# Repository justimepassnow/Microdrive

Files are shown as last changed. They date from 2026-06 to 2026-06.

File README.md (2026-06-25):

# μDrive (Microdrive)





**μDrive** is an open-source hardware and software project designed to convert any standard "dumb" DC motor into a smart, closed-loop servo motor. By retrofitting a standard DC motor with an analog potentiometer or an I2C magnetic encoder, μDrive grants you precise control over position, velocity, and current.

---

## ✨ Features

* **Universal DC Motor Support:** Works with standard DC brushed motors (within the limits of the onboard motor driver).
* **Closed-Loop Control:** PID-based control over Motor Position, Velocity, and Torque.
* **Single-Wire Communication:** Network multiple servos together using a half-duplex, single-wire UART interface.
* **Web-Based Dashboard:** Includes a Svelte-based WebGUI utilizing the Web Serial API. Connect a master microcontroller to your PC via USB, and monitor/tune your servo network directly from your browser.
* **High-Level API:** Control motors using high-level commands without worrying about register-level or bit-level operations.

---

## 📖 Documentation

A comprehensive documentation suite is available in the [docs](docs/) directory:
* **[Hardware Reference](docs/hardware.md):** Detailed specs of both board variants, pin mappings, and BOM.
* **[Firmware Guide](docs/firmware.md):** Protocol specifications, PID loop details, and compilation/flashing guide.
* **[Getting Started](docs/getting-started.md):** Step-by-step instructions from zero to a running servo network.
* **[MicroPython API Reference](docs/api-reference.md):** Comprehensive reference for the library, utility scripts, and wiring.

---

## 🛠️ Hardware Specifications

μDrive is available in **two PCB variants** sharing the same MCU and logic, but using different motor drivers:

| Feature | Servo Board | MG996 Drop-in Board |
|---|---|---|
| **Motor Driver** | CP2119 | BDR6121H |
| **Form Factor** | Standard — attach to any DC motor | Drop-in replacement for MG996R servo |
| **Operating Voltage** | Up to 18V max | Up to 7.5V max |
| **Current Rating** | 5A continuous | 1.5A continuous / 3A peak |
| **PCB Files** | [servo_pcb](PCB/) | [servo_pcb_mg99x](PCB/) |

### Board Layouts
<p align="center">
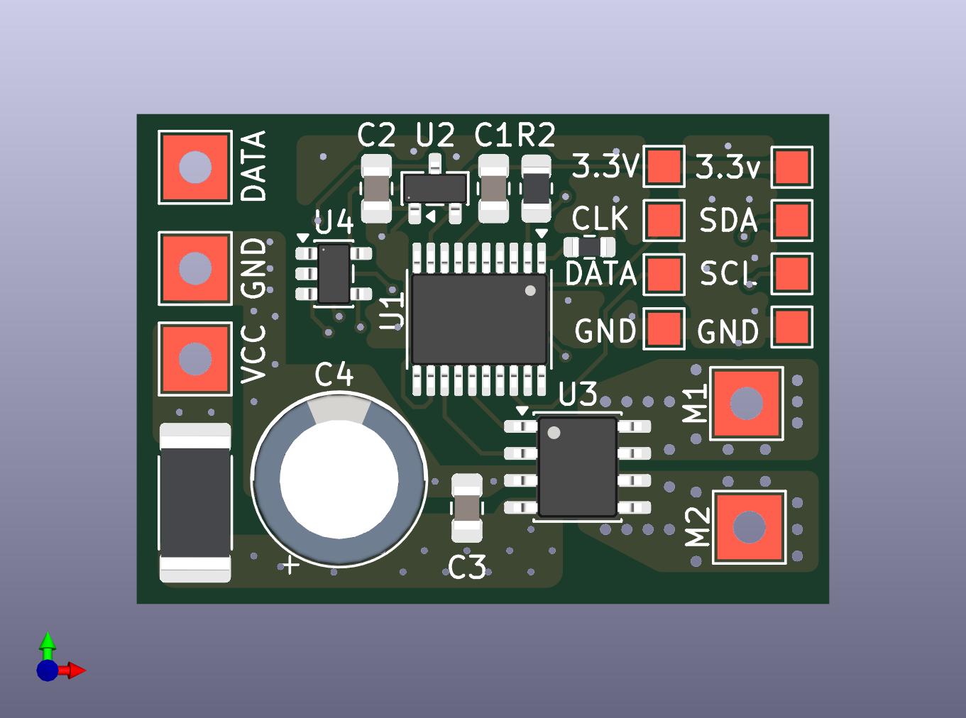
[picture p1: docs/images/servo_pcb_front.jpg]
Servo Board Front
  
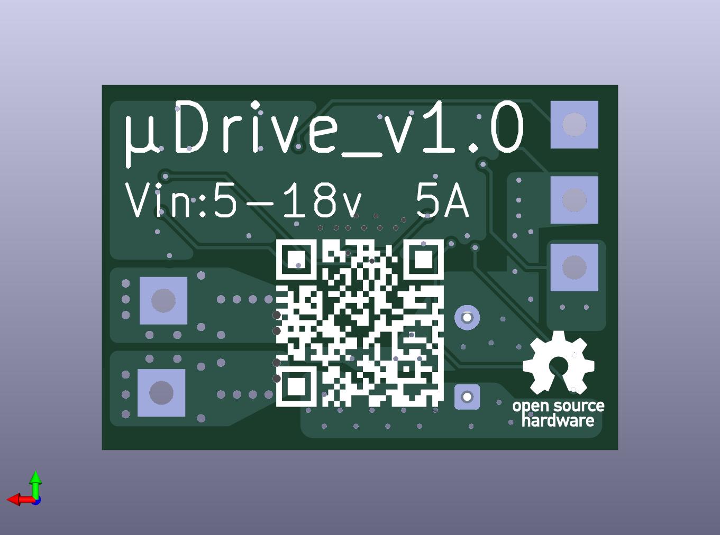
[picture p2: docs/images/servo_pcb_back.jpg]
Servo Board Back
  
</p>

### Common Architecture (Both Boards)
* **Microcontroller:** MindMotion MM32G0001 (32-bit Cortex-M0, 48MHz, 16KB Flash, 2KB RAM)
* **Current Sensor:** INA180A2 (current sense amplifier) with a 0.01Ω shunt resistor for overcurrent protection
* **Power:** Onboard SL7533-3 3.3V logic regulator (supports input up to 24V)
* **Feedback Inputs:**
  * **Analog:** Standard potentiometer support (shared with the SDA pin).
  * **Digital (I2C):** 4-pad footprint (3.3V, SCL, SDA, GND) for external I2C magnetic encoders like the AS5600.
* **Communication:** Half-duplex, single-wire UART on PA12 (open-drain), 250000 baud, 8N1.

---

## 💻 Software & APIs

The project uses a Master/Slave architecture over a half-duplex UART bus. You simply import the driver library onto your master microcontroller and send high-level commands.

* **MicroPython:** A fully functioning driver library is currently available.
* **Arduino/C++:** *Coming soon!*

### WebGUI Architecture

```mermaid
graph TD
    Web["<span style='color:#000'>💻 Web Browser<br>(Svelte WebGUI)</span>"] -- "Web Serial API" --> Master["<span style='color:#000'>🧠 Master Microcontroller<br>(Running Python Script)</span>"]
    Master -- "Single-Wire UART" --> Servo["<span style='color:#000'>⚡ μDrive Servo Board</span>"]
    Servo --> Motor["<span style='color:#000'>⚙️ DC Motor + Encoder</span>"]

    %% Styling
    style Web fill:#e1f5fe,stroke:#01579b,stroke-width:2px;
    style Master fill:#e8f5e9,stroke:#1b5e20,stroke-width:2px;
    style Servo fill:#fff3e0,stroke:#e65100,stroke-width:2px;
    style Motor fill:#efebe9,stroke:#3e2723,stroke-width:2px;
```

<br>

### Web GUI

<p align="center">
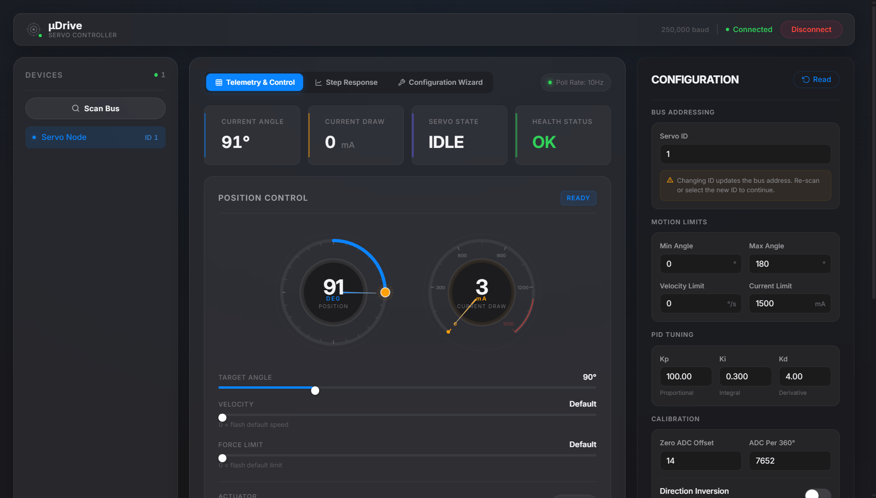
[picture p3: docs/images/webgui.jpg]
μDrive WebGUI Dashboard
  
</p>

<br>

---

## 🚀 Getting Started

### 1. Flashing the Servo Board (via Picoprobe)

> *Why use a Raspberry Pi Pico?*
> Programming obscure chips like the MM32G0001 usually requires buying dedicated, expensive hardware programmers (like mm32link or ST-Link). By using a $4 Raspberry Pi Pico instead, we keep the project incredibly cheap and accessible. Even better: once you've flashed the servo board, you can wipe the Pico and reuse it as the master MicroPython controller for your entire servo network!

**Step 1: Turn the Pico into a Programmer**
Flash your Raspberry Pi Pico with the **Picoprobe** (Debug Probe) firmware to turn it into a CMSIS-DAP debugger. You can download the latest `debugprobe_on_pico.uf2` file directly from the [official Raspberry Pi GitHub Releases page](https://github.com/raspberrypi/debugprobe/releases). Just hold the BOOTSEL button, plug in the Pico, and drag-and-drop the file!

**Step 2: Wire the Pico to the μDrive Board**
Connect these 4 wires from the Pico to the programming header on the μDrive board:
* **Pico 3V3**  -->  **μDrive 3.3V**
* **Pico GND**  -->  **μDrive GND**
* **Pico GP2**  -->  **μDrive SWCLK** (Labeled **C** on the board)
* **Pico GP3**  -->  **μDrive SWDIO** (Labeled **D** on the board)

**Step 3: Install the Software Tools**
1. Install **VS Code** and add the **PlatformIO** extension.
2. Install **Python** on your PC.
3. Open a terminal and install the flashing tool by running: `pip install pyocd`
   * *(**Windows Users:** If `pyocd` fails to detect your probe later, Windows likely installed the wrong default driver. Download the free [Zadig tool](https://zadig.akeo.ie/), select "Picoprobe CMSIS-DAP" from the dropdown, and replace the driver with **WinUSB**).*

**Step 4: Open and Flash!**
1. Clone this repository and open the `Microdrive` folder in VS Code.
2. Click the PlatformIO **Upload** button (the small `→` arrow at the bottom of the screen). PlatformIO will automatically compile the code and trigger `pyocd` to flash it onto the MM32G0001!

### 2. Setting Up the Master MCU (Drivers)
Once the servo board is flashed, it listens for commands over a half-duplex UART line. You will need a "Master" microcontroller to send these commands.
* Currently, a **MicroPython** driver is provided. You can flash a standard Raspberry Pi Pico with MicroPython, import the provided driver library, and use simple high-level functions to command the servo.
* *(Arduino/C++ library support is coming soon!)*

### 3. Launching the Web GUI
To easily tune and monitor your servo network from your computer, you can run the provided Svelte WebGUI:
1. Ensure your Master MCU is connected to your PC via USB and running the serial bridge python script.
2. Open a terminal and navigate to the `gui` folder inside this repository.
3. Run `npm install` to download the web dependencies.
4. Run `npm run dev` to start the local server.
5. Open the provided `localhost` link in a browser that supports the Web Serial API (like Chrome or Edge) to connect to your Master MCU and start tuning!

---

## 🚧 Known Issues & Roadmap

Microdrive is actively under development. Current focus areas include:

* **🐛 EMI Stability:** The board occasionally stops responding to commands during massive current spikes. This is likely due to electromagnetic interference (EMI) crashing the MCU or bus. Hardware/software filtering improvements are being investigated.
* **🚀 Better I2C Encoder Support:** Writing the software drivers to fully utilize the AS5600 footprint.
* **⚙️ Control Optimization:** Improving the efficiency of the communication protocol and fine-tuning the torque and velocity control loops.
* **🔌 Arduino Compatibility:** Development of Arduino/C++ compatible driver libraries to control the servo network from Arduino-compatible microcontrollers.

---

## 🤝 Contributing

Contributions are welcome! Whether it's firmware, hardware, documentation, or the WebGUI — check out the [Contributing Guide](CONTRIBUTING.md) to get started. Found a bug or have an idea? [Open an issue](https://github.com/justimepassnow/Microdrive/issues).

---

## ⚖️ License

This project is fully open-source and [OSHWA certified](https://certification.oshwa.org/in000092.html) (**UID: IN000092**):
* The **Software/Firmware** is licensed under the [MIT License](LICENSE).
* The **Hardware (PCBs/Schematics)** is licensed under the [CERN-OHL-P v2](LICENSE-HARDWARE.txt).

You are free to build, modify, and integrate μDrive into your own projects (commercial or hobbyist).

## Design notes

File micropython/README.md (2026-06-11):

# Microdrive — MicroPython Driver

A lightweight MicroPython library for controlling Microdrives running the MM32 firmware over a half-duplex single-wire UART bus.

## Features

- **Full protocol coverage** — CONTROL, CONFIG, POLL_STATUS, CLEAR_ERROR
- **Half-duplex aware** — built-in TX/RX direction switching with optional GPIO pin
- **Daisy-chain ready** — address servos individually or broadcast to all at once
- **Blocking helpers** — `move_and_wait()` blocks until the servo reaches its target
- **Bus scanner** — discover connected servo IDs
- **Granular or bulk config** — update a single setting or many in one packet
- **Zero dependencies** — only `machine`, `struct`, and `time` (standard MicroPython)

## Wiring

The servo firmware uses **half-duplex single-wire UART** on PA12 (open-drain) at **250000 baud, 8N1**.

### Single-Wire Bus Layout

#### Option A: For boards with open-drain UART support (e.g., ESP32)
If your microcontroller supports native half-duplex UART or allows configuring the TX pin as open-drain, you can connect the TX pin directly to the data bus. No external pull-up is needed because the μDrive PCB already includes an onboard 10kΩ pull-up resistor on the data bus:

```
ESP32 (Open-Drain TX/RX)               μDrive
┌──────────────────┐                   ┌──────────────────┐
│  TX/RX (Pin 4)   ├───────────────────┤ Data Bus         │
│                  │                   │ (Onboard 10kΩ    │
│             GND  ├───────────────────┤  pull-up to 3.3V)│
└──────────────────┘                   └──────────────────┘
```

#### Option B: For boards without open-drain UART support (e.g., Raspberry Pi Pico / RP2040)
If your board does not support open-drain UART, connect the RX pin directly to the bus, and connect the TX pin to the RX pin/bus through a **1kΩ isolation resistor** to prevent short circuits when the MCU TX drives the pin high:

```
MicroPython MCU (Pico)                 μDrive
┌──────────────────┐                   ┌──────────────────┐
│         GP4 (TX) ├────[ 1kΩ Res ]    │                  │
│                  │         │         │                  │
│         GP5 (RX) ├─────────┴─────────┤ Data Bus         │
│                  │                   │ (Onboard 10kΩ    │
│             GND  ├───────────────────┤  pull-up to 3.3V)│
└──────────────────┘                   └──────────────────┘
```

> **Tip:** The 1kΩ resistor acts as isolation. When the Pico transmits a logic low, it pulls the data line down through the resistor. When the servo transmits, the resistor protects the Pico's TX pin if it remains driven high. Since the μDrive board has an onboard 10kΩ pull-up on the Data Bus, no external pull-up resistor is required.

## Quick Start

```python
from machine import UART, Pin
from microdrive import ServoBus

# Create bus (adjust pins for your board)
uart = UART(1, baudrate=250000, tx=Pin(4))
bus  = ServoBus(uart)

# Get a handle to servo at ID 0 (factory default)
servo = bus.servo(0)

# Move to 180 degrees
status = servo.move(180)
print(status)  # <ServoStatus angle=180° current=42mA>

# Poll current state
status = servo.poll()
print(status.angle, status.current_ma, status.is_moving)
```

## API Reference

### `ServoBus(uart, dir_pin=None, reply_timeout_ms=50)`

Manages the shared UART bus.

| Method | Description |
|---|---|
| `servo(id)` | Returns a `Servo` handle for the given ID |
| `broadcast_move(angle, velocity=0)` | Move all servos (no reply) |
| `broadcast_clear_error()` | Clear faults on all servos (no reply) |
| `scan(id_range=range(0,254))` | Scan for connected servos, returns list of `(id, ServoStatus)` |

### `Servo` (returned by `bus.servo(id)`)

#### Movement

| Method | Description |
|---|---|
| `move(angle, velocity=0)` | Send move command. `velocity=0` uses flash default. Returns `ServoStatus` |
| `move_and_wait(angle, velocity=0, timeout_ms=10000)` | Blocking move — returns final `ServoStatus` or `None` on timeout |
| `wait_until_done(timeout_ms=10000, poll_interval_ms=50)` | Block until servo reports idle |
| `is_moving()` | Returns `True` if the servo is currently in motion |

#### Status & Error

| Method | Description |
|---|---|
| `poll()` | Request current status. Returns `ServoStatus` |
| `clear_error()` | Clear overcurrent/stall faults and reset PID state |

#### Configuration (Individual)

| Method | Description |
|---|---|
| `set_id(new_id, direction_invert=False)` | Change bus address (0–127) and motor direction |
| `set_angle_limits(min_angle, max_angle)` | Set software angle limits |
| `set_velocity(max_velocity)` | Set flash-default velocity (deg/s) |
| `set_current_limit(current_limit)` | Set over-current threshold (mA) |
| `set_pid(kp, ki, kd)` | Set PID gains (float → Q16 conversion handled automatically) |
| `set_hard_calibration(hard_min=0, hard_max=300)` | Set potentiometer-to-angle mapping |

#### Configuration (Bulk)

```python
servo.configure(
    servo_id=5,
    direction_invert=False,
    min_angle=45,
    max_angle=280,
    max_velocity=180,
    current_limit=1000,
    kp=100.0, ki=0.05, kd=8.0,
    hard_min=0, hard_max=300,
)
```

Only non-`None` fields are written; others are left untouched on the servo.

### `ServoStatus`

Returned by `move()`, `poll()`, `clear_error()`, and `configure()`.

| Property | Type | Description |
|---|---|---|
| `angle` | int | Current physical angle (degrees) |
| `current_ma` | int | Motor current draw (milliamps) |
| `is_moving` | bool | Servo is actively tracking a target |
| `overcurrent` | bool | Over-current fault flag |
| `stall` | bool | Stall detection fault flag |
| `has_fault` | bool | `True` if any fault is active |
| `servo_id` | int | ID of the servo that replied |
| `instruction` | int | Echoed instruction byte |

## Protocol Reference

See [`../byteorder.md`](../byteorder.md) for the full byte-level packet specification.

## Tested Boards

The library uses only standard MicroPython APIs and should work on any board with a UART peripheral:

- ESP32 / ESP32-S3
- Raspberry Pi Pico (RP2040)
- STM32 (Pyboard)
- ESP8266

## License

Same license as the parent project.

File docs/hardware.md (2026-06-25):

# 🔧 Hardware Documentation

μDrive is an open-source servo controller that turns any standard DC brushed motor into a closed-loop microdrive. This document covers the hardware design, board variants, components, and PCB files.

---

## 📋 Board Variants

Microdrive ships as **two PCB variants**. Both share the same MCU, voltage regulator, current sensor, firmware, and communication protocol. The only difference is the **motor driver IC** and the resulting form factor.

| | Servo Board | MG996 Drop-in Board |
|---|---|---|
| **Motor Driver** | CP2119 | BDR6121H |
| **Form Factor** | Standard — attach to any DC brushed motor | Drop-in replacement for MG996R servo |
| **Operating Voltage** | Up to 18V max | Up to 7.5V max |
| **Current Rating** | 5A continuous | 1.5A continuous / 3A peak |
| **Schematic** | `servo_pcb.kicad_sch` | `servo_pcb_mg99x.kicad_sch` |
| **PCB Layout** | `servo_pcb.kicad_pcb` | `servo_pcb_mg99x.kicad_pcb` |

> [!TIP]
> Both boards run identical firmware. Choose the variant that fits your mechanical design — or use the Servo Board as a universal motor controller.

---

## ⚙️ Common Specifications

| Parameter | Value |
|---|---|
| **MCU** | MindMotion MM32G0001 (32-bit ARM Cortex-M0, 48 MHz) |
| **Flash / RAM** | 16 KB / 2 KB |
| **Voltage Regulator** | SL7533-3 (3.3V LDO, input up to 24V) |
| **Current Sensor** | INA180A2 (current sense amplifier) with 0.01Ω shunt (R1, 2512 package) |
| **Motor PWM** | TIM1 CH2 (PA8) / CH3 (PA6), 20 kHz, H-bridge control |
| **Communication** | Half-duplex single-wire UART on PA12 (open-drain), 250000 baud, 8N1 |
| **Programming** | SWD via SWCLK and SWDIO test pads (use Picoprobe / CMSIS-DAP) |

### Feedback Options

μDrive supports two mutually exclusive feedback mechanisms:

| Feedback Type | Details |
|---|---|
| **Analog Potentiometer** | Connected to PA7 (ADC Channel 7). Shared with the SDA pin on the I2C header. |
| **I2C Magnetic Encoder** | AS5600 footprint with 4-pad header: 3.3V, SCL, SDA, GND. *(Hardware ready, software planned.)* |

> [!NOTE]
> The potentiometer input and the SDA pin share the same physical trace on the PCB. You can use one or the other — not both simultaneously.

---

## 🗺️ Pin Mapping (MM32G0001 — TSSOP-20)

| Pin | Function | Notes |
|---|---|---|
| PA12 | UART TX/RX | Half-duplex single-wire bus (open-drain, AF1) |
| PA6 | TIM1 CH3 (PWM) | H-bridge output A (AF4). Also heartbeat LED in debug. |
| PA8 | TIM1 CH2 (PWM) | H-bridge output B (AF1) |
| PA7 | ADC Channel 7 | Potentiometer feedback (analog input) |
| PA5 | I2C SCL | Clock line for optional AS5600 encoder / SCL test pad (AF1) |
| PA4 | I2C SDA | Tied to PA7 on PCB — digital buffer disabled for noise reduction (SDA) |
| PA2 | ADC Channel 5 | Current sense amplifier output (INA180A2) |
| PA0 | GPIO Input (Pull-Up) | Software reset button |
| SWCLK | SWD Clock | Programming/debug pad |
| SWDIO | SWD Data | Programming/debug pad |

---

## 📦 Bill of Materials

| Designator | Package | Value | Component |
|---|---|---|---|
| U1 | TSSOP-20 | MM32G0001 | MCU |
| U2 | SOT-23 | SL7533-3 | 3.3V LDO Regulator |
| U3 | SOIC-8 | BDR6121H *(MG996)* / CP2119 *(Servo Board)* | Motor Driver |
| U4 | SOT-23-5 | INA180A2 | Current Sense Amplifier |
| U5 | SOIC-8 | AS5600 | I2C Magnetic Encoder *(optional)* |
| R1 | 2512 | 0.01Ω | Current Sense Shunt Resistor |
| R2, R3, R4 | 0805 | 10KΩ | Pull-up / Pull-down Resistors |
| C1, C4 | 0805 | 10μF | Decoupling Capacitors |
| C2, C3, C5 | 0805 | 100nF | Bypass Capacitors |
| J1 | Pin Header 1×03, P2.54mm | Power In | Power Connector |

### Test Pads

The PCB exposes the following test pads for probing and programming:

| Pad | Description |
|---|---|
| 3.3V | Regulated logic supply |
| GND | Ground |
| SDA | I2C data / Potentiometer analog signal |
| SCL | I2C clock |
| SWCLK | SWD clock (labeled **C** on the board) |
| SWDIO | SWD data (labeled **D** on the board) |
| +VE | Motor positive terminal |
| -VE | Motor negative terminal |

## 📁 PCB Files

All hardware design files are located in the [`PCB/`](../PCB/) directory of the repository. The project uses **KiCad** as the EDA tool.

### File Listing

| File | Description |
|---|---|
| `servo_pcb.kicad_sch` | Servo Board schematic |
| `servo_pcb.kicad_pcb` | Servo Board PCB layout |
| `servo_pcb.kicad_pro` | Servo Board KiCad project |
| `servo_pcb-mg99x.kicad_sch` | MG996 drop-in board schematic |
| `servo_pcb_mg99x.kicad_pcb` | MG996 drop-in board PCB layout |
| `servo_pcb_mg99x.kicad_pro` | MG996 drop-in board KiCad project |

### Custom Symbol Libraries

| File | Component |
|---|---|
| `mm32g0001a1t.kicad_sym` | MM32G0001 MCU |
| `BDR6121H.kicad_sym` | BDR6121H motor driver |
| `CP2119L.kicad_sym` | CP2119 motor driver |
| `AS5600.kicad_sym` | AS5600 magnetic encoder |
| `sl7533-3.kicad_sym` | SL7533-3 voltage regulator |

## ⚖️ Licensing

| Component | License |
|---|---|
| Hardware (PCBs / Schematics) | [CERN-OHL-P v2](../LICENSE-HARDWARE.txt) |
| Software / Firmware | [MIT License](../LICENSE) |

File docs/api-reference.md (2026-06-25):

# 📖 MicroPython API Reference

Complete API documentation for the `microdrive.py` driver library.

**Source:** [`micropython/microdrive.py`](../micropython/microdrive.py)

---

## Table of Contents

- [Quick Start](#quick-start)
- [ServoBus](#servobus)
- [Servo](#servo)
  - [Movement](#movement)
  - [Status & Error](#status--error)
  - [Configuration (Individual)](#configuration-individual)
  - [Configuration (Bulk)](#configuration-bulk)
  - [Convenience](#convenience)
- [ServoStatus](#servostatus)
- [ServoConfigData](#servoconfigdata)
- [Protocol Details](#protocol-details)
- [Wiring Diagrams](#wiring-diagrams)
- [Utility Scripts](#utility-scripts)

---

## Quick Start

```python
from machine import UART, Pin
from microdrive import ServoBus

uart = UART(1, baudrate=250000, tx=Pin(4), rx=Pin(5))
bus  = ServoBus(uart)
servo = bus.servo(0)

# Move to 180° at default velocity
servo.move(180)

# Poll current state
status = servo.poll()
print(status)  # <ServoStatus angle=180° current=42mA>
```

---

## ServoBus

```python
ServoBus(uart, dir_pin=None, reply_timeout_ms=5)
```

Manages the shared half-duplex UART bus for one or more Microdrives.

### Parameters

| Parameter | Type | Default | Description |
|---|---|---|---|
| `uart` | `machine.UART` | *(required)* | Pre-configured UART instance at **250,000 baud, 8N1**. TX pin wired to the servo bus line. |
| `dir_pin` | `machine.Pin` or `None` | `None` | Optional direction control pin (active-high = transmit). Set to `None` if the UART handles half-duplex natively or if using a shared open-drain TX/RX line. |
| `reply_timeout_ms` | `int` | `5` | Milliseconds to wait for a servo reply before giving up. The firmware replies in ~2.7 ms on average. |

### Methods

#### `servo(servo_id) → Servo`

Create a `Servo` handle bound to this bus.

| Parameter | Type | Description |
|---|---|---|
| `servo_id` | `int` | The servo's bus address (**0–127**). ID 0 targets factory-default / unconfigured servos. |

```python
servo = bus.servo(0)
```

---

#### `broadcast_move(angle, velocity=0, current=0)`

Move **all** servos on the bus simultaneously. No reply is expected (broadcast address `0xFE`).

| Parameter | Type | Default | Description |
|---|---|---|---|
| `angle` | `int` | *(required)* | Target angle in degrees |
| `velocity` | `int` | `0` | Temporary velocity in deg/s. `0` = use each servo's flash default |
| `current` | `int` | `0` | Temporary current/force limit in mA. `0` = use each servo's flash default |

```python
bus.broadcast_move(90, velocity=200)
```

---

#### `broadcast_clear_error()`

Clear faults on **all** servos (no reply expected). Also resets PID state and locks the target angle to the current physical position on each servo.

```python
bus.broadcast_clear_error()
```

---

#### `broadcast_disarm()`

Disarm all servos on the bus, turning off H-bridges so that all servo shafts spin completely freely. This is an alias for `broadcast_clear_error()`.

```python
bus.broadcast_disarm()
```

---

#### `scan(id_range=range(0, 128)) → list[(int, ServoStatus)]`

Scan the bus for connected servos by polling each ID in the range.

Returns a list of `(servo_id, ServoStatus)` tuples for every servo that replied.

| Parameter | Type | Default | Description |
|---|---|---|---|
| `id_range` | `range` | `range(0, 128)` | Range of IDs to scan |

> [!NOTE]
> Scanning is slow — each non-responding ID waits for the full reply timeout. Narrow the range if you know the expected IDs.

```python
found = bus.scan(id_range=range(0, 10))
for sid, status in found:
    print(f"ID {sid}: {status.angle}° {status.current_ma}mA")
```

---

## Servo

```python
# Do not instantiate directly — use bus.servo(id) instead
servo = bus.servo(1)
```

High-level interface to a single Microdrive on the bus.

### Properties

| Property | Type | Description |
|---|---|---|
| `id` | `int` | This servo's bus address (read-only) |

---

### Movement

#### `move(angle, velocity=0, current=0) → None`

Command the servo to move to the target angle. Returns immediately (fire-and-forget, no reply expected).

| Parameter | Type | Default | Description |
|---|---|---|---|
| `angle` | `int` | *(required)* | Target angle in degrees (clamped to configured limits) |
| `velocity` | `int` | `0` | Temporary movement speed in deg/s. `0` = use flash default |
| `current` | `int` | `0` | Temporary force/current limit in mA. `0` = use flash default |

```python
servo.move(90)
servo.move(180, velocity=300, current=800)
```

> [!IMPORTANT]
> The motor **does not move** until the first `move()` command is received after power-on. This is a safety feature — the H-bridge stays off until then.

---

#### `move_and_wait(angle, velocity=0, timeout_ms=10000) → ServoStatus | None`

Send a move command and **block** until the servo reports it has reached the target (i.e., `is_moving` becomes `False`).

| Parameter | Type | Default | Description |
|---|---|---|---|
| `angle` | `int` | *(required)* | Target angle in degrees |
| `velocity` | `int` | `0` | Temporary velocity in deg/s |
| `timeout_ms` | `int` | `10000` | Max time to wait before returning `None` |

Returns the final `ServoStatus`, or `None` on timeout.

```python
status = servo.move_and_wait(180, velocity=200, timeout_ms=5000)
if status:
    print(f"Arrived at {status.angle}°")
```

---

#### `wait_until_done(timeout_ms=10000, poll_interval_ms=50) → ServoStatus | None`

Block until the servo reports it has finished moving, or until timeout. Polls the servo at the given interval.

| Parameter | Type | Default | Description |
|---|---|---|---|
| `timeout_ms` | `int` | `10000` | Max time to wait |
| `poll_interval_ms` | `int` | `50` | Polling interval |

```python
servo.move(90)
# ... do other work ...
final = servo.wait_until_done()
```

---

#### `is_moving() → bool`

Poll the servo and return `True` if it is currently in motion.

```python
if servo.is_moving():
    print("Still moving...")
```

---

### Status & Error

#### `poll() → ServoStatus | None`

Request the servo's current status without changing anything. Returns a `ServoStatus` object, or `None` on timeout.

```python
status = servo.poll()
if status:
    print(f"{status.angle}° — {status.current_ma} mA")
```

---

#### `clear_error() → None`

Clear the overcurrent fault flag, reset PID integrator memory, and lock the target angle to the servo's current physical position.

```python
servo.clear_error()
```

---

#### `disarm() → None`

Disarm the motor H-bridge, disabling power so the shaft spins freely. The servo re-arms automatically upon the next `move()` command. This is an alias for `clear_error()`.

```python
servo.disarm()
```

---

### Configuration (Individual)

Each setter sends a fixed-length CONFIG packet with only its corresponding update-mask bit set. The firmware ignores all fields whose mask bits are not active.

> [!NOTE]
> Configuration changes are **saved to flash** by default and persist across power cycles. Use the `ram_only=True` flag on `set_pid()` or `configure()` to apply changes temporarily (useful for rapid PID tuning without wearing out flash).

---

#### `set_id(new_id, direction_invert=False) → ServoStatus | None`

Change the servo's bus address and/or motor direction.

| Parameter | Type | Default | Description |
|---|---|---|---|
| `new_id` | `int` | *(required)* | New servo ID (**0–127**). 0 = unconfigured. |
| `direction_invert` | `bool` | `False` | `True` to invert the motor rotation direction |

```python
servo.set_id(5)
# After changing the ID, create a new handle:
servo = bus.servo(5)
```

> [!WARNING]
> After changing the ID, the old `Servo` handle is stale. Always create a new one with `bus.servo(new_id)`.

---

#### `set_angle_limits(min_angle, max_angle) → ServoStatus | None`

Set the software-enforced angle limits (degrees). The servo will clamp any move command to these bounds.

| Parameter | Type | Description |
|---|---|---|
| `min_angle` | `int` | Minimum allowable target angle |
| `max_angle` | `int` | Maximum allowable target angle |

```python
servo.set_angle_limits(0, 180)
```

---

#### `set_velocity(max_velocity) → ServoStatus | None`

Set the flash-stored default velocity limit in degrees per second. This is used when `velocity=0` is passed to `move()`.

| Parameter | Type | Description |
|---|---|---|
| `max_velocity` | `int` | Default maximum velocity (deg/s) |

```python
servo.set_velocity(200)
```

---

#### `set_current_limit(current_limit) → ServoStatus | None`

Set the over-current fault threshold in milliamps.

| Parameter | Type | Description |
|---|---|---|
| `current_limit` | `int` | Current draw threshold (mA) |

```python
servo.set_current_limit(1000)
```

---

#### `set_pid(kp=None, ki=None, kd=None, ram_only=False) → ServoStatus | None`

Set PID gains. Accepts **float** values — they are converted to Q16.16 fixed-point internally.

| Parameter | Type | Default | Description |
|---|---|---|---|
| `kp` | `float` or `None` | `100.0` | Proportional gain |
| `ki` | `float` or `None` | `0.05` | Integral gain |
| `kd` | `float` or `None` | `8.0` | Derivative gain |
| `ram_only` | `bool` | `False` | If `True`, update RAM only (skip flash save) |

> [!IMPORTANT]
> All three gains are written as a group. If you pass `None` for any gain, the firmware default is used (Kp=100.0, Ki=0.05, Kd=8.0). Always provide all three values together when tuning.

```python
# Tune PID in RAM (fast iteration, no flash wear)
servo.set_pid(kp=80.0, ki=0.03, kd=12.0, ram_only=True)

# Save final values to flash
servo.set_pid(kp=80.0, ki=0.03, kd=12.0)
```

---

#### `set_calibration(zero_adc, adc_per_360) → ServoStatus | None`

Set the physical ADC calibration mapping for the potentiometer.

| Parameter | Type | Description |
|---|---|---|
| `zero_adc` | `int` | Raw ADC value corresponding to 0° |
| `adc_per_360` | `int` | Number of ADC ticks for a full 360° rotation |

```python
servo.set_calibration(zero_adc=120, adc_per_360=3200)
```

> [!TIP]
> Use the `manual_angle_calibrate.py` utility script to determine these values precisely for your motor.

---

### Configuration (Bulk)

#### `configure(...) → ServoStatus | None`

Update multiple configuration fields in a **single** CONFIG packet. Only the provided (non-`None`) fields are written; all others are left untouched on the servo.

```python
configure(
    servo_id=None,           # int: New bus address (0–127)
    direction_invert=None,   # bool: Invert motor direction
    min_angle=None,          # int: Minimum angle limit (degrees)
    max_angle=None,          # int: Maximum angle limit (degrees)
    max_velocity=None,       # int: Default velocity (deg/s)
    current_limit=None,      # int: Over-current threshold (mA)
    kp=None,                 # float: Proportional PID gain
    ki=None,                 # float: Integral PID gain
    kd=None,                 # float: Derivative PID gain
    zero_adc=None,           # int: Raw ADC at 0°
    adc_per_360=None,        # int: ADC ticks per 360°
    ram_only=False           # bool: Skip flash write
)
```

**Example — full initial configuration:**

```python
servo.configure(
    servo_id=1,
    direction_invert=False,
    min_angle=0,
    max_angle=200,
    max_velocity=180,
    current_limit=1000,
    kp=100.0, ki=0.05, kd=8.0,
)
```

**Example — change just the velocity:**

```python
servo.configure(max_velocity=300)
```

> [!NOTE]
> Angle limits (`min_angle`, `max_angle`) and calibration values (`zero_adc`, `adc_per_360`) must be provided **as a pair** — you cannot update one without the other.

---

#### `read_config() → ServoConfigData | None`

Request the servo's full persistent configuration stored in flash memory.

```python
config = servo.read_config()
if config:
    print(f"ID: {config.servo_id}")
    print(f"Limits: {config.min_angle}° – {config.max_angle}°")
    print(f"PID: Kp={config.kp:.2f} Ki={config.ki:.4f} Kd={config.kd:.2f}")
```

---

## ServoStatus

Returned by `poll()`, `move_and_wait()`, `wait_until_done()`, and configuration methods (when not broadcasting).

| Property | Type | Description |
|---|---|---|
| `angle` | `int` | Current physical angle in degrees (signed, can be negative) |
| `current_ma` | `int` | Motor current draw in milliamps |
| `is_moving` | `bool` | `True` if the servo is actively tracking a target |
| `overcurrent` | `bool` | `True` if an over-current fault is active |
| `is_holding` | `bool` | `True` if admittance yield mode is active (motor is complying/backdriving due to current limiting) |
| `has_fault` | `bool` | `True` if **any** fault flag is active (currently = `overcurrent`) |
| `servo_id` | `int` | Bus address of the servo that replied |
| `instruction` | `int` | Echoed instruction byte from the request |

**String representation:**

```python
>>> status = servo.poll()
>>> print(status)
<ServoStatus angle=90° current=42mA flags=HOLDING>
```

---

## ServoConfigData

Returned by `servo.read_config()`. Contains the persistent configuration stored in flash.

| Property | Type | Description |
|---|---|---|
| `servo_id` | `int` | Bus address (0–127) |
| `direction_invert` | `bool` | Whether motor direction is inverted |
| `min_angle` | `int` | Software minimum angle limit (degrees) |
| `max_angle` | `int` | Software maximum angle limit (degrees) |
| `max_velocity` | `int` | Default velocity in deg/s |
| `current_limit` | `int` | Over-current fault threshold in mA |
| `kp` | `float` | Proportional PID gain (converted from Q16) |
| `ki` | `float` | Integral PID gain (converted from Q16) |
| `kd` | `float` | Derivative PID gain (converted from Q16) |
| `zero_adc` | `int` | Raw ADC value at 0° |
| `adc_per_360` | `int` | ADC ticks per full 360° rotation |
| `magic` | `int` | Flash validity marker |

**String representation:**

```python
>>> config = servo.read_config()
>>> print(config)
<ServoConfigData id=1 dir_invert=False limits=0°-200° max_vel=180
 current_lim=1000mA kp=100.00 ki=0.0500 kd=8.00
 zero_adc=120 adc_per_360=3200 magic=0xCAFE>
```

---

## Protocol Details

The servo bus uses a binary packet protocol over half-duplex UART:

| Field | Description |
|---|---|
| **Header** | `0xFF 0xFF` (2 bytes) |
| **Servo ID** | Target address (1 byte, `0xFE` = broadcast) |
| **Length** | Number of remaining bytes: instruction + params + checksum |
| **Instruction** | Command byte (see below) |
| **Parameters** | Little-endian payload (variable length) |
| **Checksum** | `~(sum of ID + Length + Instruction + Params) & 0xFF` |

### Instruction Codes

| Code | Name | Direction | Description |
|---|---|---|---|
| `0x01` | `CONTROL` | Master → Servo | Move command (angle, velocity, current) |
| `0x02` | `CONFIG` | Master → Servo | Write configuration fields |
| `0x03` | `POLL` | Master → Servo | Request status (servo replies with 11-byte status) |
| `0x04` | `CLEAR_ERR` | Master → Servo | Clear faults, reset PID, disarm H-bridge |
| `0x05` | `READ_CONFIG` | Master → Servo | Read flash config (servo replies with 36-byte config) |

### Reply Packet Sizes

| Reply Type | Total Bytes |
|---|---|
| **Status reply** | 11 bytes |
| **Config reply** | 36 bytes |

---

## Wiring Diagrams

### Single-Wire Bus Layout

#### Option A: For boards with open-drain UART support (e.g., ESP32)
If your microcontroller supports native half-duplex UART or allows configuring the TX pin as open-drain, you can connect the TX pin directly to the data bus. No external pull-up is needed because the μDrive PCB already includes an onboard 10kΩ pull-up resistor on the data bus:

```mermaid
graph LR
    subgraph MCU["ESP32 (Open-Drain TX/RX)"]
        Pin["<span style='color:#000'>TX/RX (Pin 4)</span>"]
        GND1["<span style='color:#000'>GND</span>"]
    end
    subgraph Servo["μDrive Board"]
        Data["<span style='color:#000'>Data Bus (PA12)<br>(Onboard 10kΩ pull-up)</span>"]
        GND2["<span style='color:#000'>GND</span>"]
    end
    Pin --- Data
    GND1 --- GND2

    style Pin fill:#e1f5fe,stroke:#01579b,stroke-width:2px;
    style Data fill:#fff3e0,stroke:#e65100,stroke-width:2px;
    style GND1 fill:#efebe9,stroke:#3e2723,stroke-width:2px;
    style GND2 fill:#efebe9,stroke:#3e2723,stroke-width:2px;
```

#### Option B: For boards without open-drain UART support (e.g., Raspberry Pi Pico / RP2040)
If your board does not support open-drain UART, do **not** tie the TX and RX pins directly together. Instead, connect the RX pin directly to the servo data bus, and connect the TX pin to the RX pin/bus through a **1kΩ isolation resistor**. This protects the TX pin from short circuits when the MCU TX drives the pin high while the servo drives the bus low:

```mermaid
graph LR
    subgraph MCU["MicroPython MCU"]
        TX["<span style='color:#000'>GP4 (TX)</span>"]
        RX["<span style='color:#000'>GP5 (RX)</span>"]
        GND1["<span style='color:#000'>GND</span>"]
    end
    subgraph Servo["μDrive Board"]
        Data["<span style='color:#000'>Data Bus (PA12)<br>(Onboard 10kΩ pull-up)</span>"]
        GND2["<span style='color:#000'>GND</span>"]
    end
    Res["<span style='color:#000'>1kΩ Resistor</span>"]

    TX --- Res
    RX --- Res
    RX --- Data
    GND1 --- GND2

    style TX fill:#e1f5fe,stroke:#01579b,stroke-width:2px;
    style RX fill:#e1f5fe,stroke:#01579b,stroke-width:2px;
    style Res fill:#f3e5f5,stroke:#7b1fa2,stroke-width:2px;
    style Data fill:#fff3e0,stroke:#e65100,stroke-width:2px;
    style GND1 fill:#efebe9,stroke:#3e2723,stroke-width:2px;
    style GND2 fill:#efebe9,stroke:#3e2723,stroke-width:2px;
```

> [!TIP]
> - The **1kΩ resistor** acts as an isolation resistor between the TX and RX/data line on the MCU side. When the MCU transmits a logic low, it pulls the data line down through the resistor. When the servo transmits, the resistor protects the microcontroller's TX pin if it remains driven high.
> - The μDrive board has an onboard **10kΩ pull-up resistor** on the Data Bus, so no external pull-up is required. An external pull-up (e.g., 4.7kΩ to 3.3V) is only needed if your custom master or bus setup lacks one.

---

## Utility Scripts

The `micropython/` folder includes several ready-to-use scripts:

| Script | Description |
|---|---|
| [example.py](../micropython/example.py) | Interactive quick-start & configuration utility. Scans for servos, shows telemetry, and enters a move-and-track loop with real-time status printing. |
| [calibrate_pid.py](../micropython/calibrate_pid.py) | **Automated PID tuner** using a gradient-ascent step-response algorithm. Finds the friction floor (Kp), determines the spring limit, damps overshoot (Kd), and injects integral gain (Ki). Saves results to flash. |
| [hard_angle_set.py](../micropython/hard_angle_set.py) | **Automatic hard-limit calibration.** Sweeps the servo to measure average dynamic current, then slowly probes in each direction until a current spike reveals the physical end-stops. Saves `min_angle` and `max_angle` to flash. |
| [manual_angle_calibrate.py](../micropython/manual_angle_calibrate.py) | **Manual multi-point potentiometer calibration.** Temporarily sets ADC scale to 1:1 so `angle` telemetry mirrors the raw ADC, then prompts you to align the shaft to 0° and 90° by hand. Computes and saves `zero_adc` and `adc_per_360`. |
| [serial_proxy.py](../micropython/serial_proxy.py) | **Serial bridge for the WebGUI.** Reads JSON commands from USB `stdin`, translates them to servo bus packets, and returns JSON responses. Supports `scan`, `move`, `poll`, `read_config`, `configure`, and `clear_error` commands. |
| [stream_current.py](../micropython/stream_current.py) | **Real-time current monitor.** Continuously polls and prints the servo's current draw — useful for verifying current sensing against a multimeter. |
| [speedtest.py](../micropython/speedtest.py) | **Feature & config sweep test.** Verifies scanning, config read/write, fault clearing, and runs a continuous angle sweep (20°→220°→20° in 40° steps) with real-time telemetry at each step. |

### Running Utility Scripts

1. Copy `microdrive.py` and the desired script onto the microcontroller.
2. Connect the servo bus and power supply.
3. Open a serial terminal (Thonny, `mpremote`, PuTTY) and run:

```python
import calibrate_pid  # or any other script
```

---

## Tested Boards

The driver uses only standard MicroPython APIs and should work on any board with a UART peripheral:

- ✅ Raspberry Pi Pico / Pico W (RP2040)
- ✅ ESP32 / ESP32-S3
- ✅ STM32 (Pyboard)
- ✅ ESP8266

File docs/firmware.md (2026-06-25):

# 💻 Firmware Documentation

The μDrive firmware is a bare-metal C application running on the MindMotion MM32G0001 (ARM Cortex-M0). It implements closed-loop position control with velocity trajectory profiling, overcurrent protection, and a binary packet communication protocol — all in 16 KB of Flash and 2 KB of RAM.

---

## 🏗️ Architecture Overview

| Parameter | Value |
|---|---|
| **Language** | C (bare-metal, no RTOS) |
| **MCU** | MM32G0001 — ARM Cortex-M0, TSSOP-20 |
| **System Clock** | 48 MHz (HSI, configured in `SystemInit()`) |
| **Flash** | 16 KB (0x08000000 – 0x08003FFF) |
| **RAM** | 2 KB (0x20000000 – 0x200007FF) |
| **Stack** | 512 bytes |
| **PID Loop Rate** | 1 ms (via SysTick interrupt) |
| **Motor PWM** | 20 kHz (TIM1, no prescaler) |
| **Arithmetic** | Q8 and Q16 fixed-point (no FPU on Cortex-M0) |

### Boot Sequence

1. `Reset_Handler` — Copies `.data` from Flash to RAM, zeroes `.bss`
2. `SystemInit()` — Configures HSI to 48 MHz, sets flash latency
3. `main()` — Initializes UART, loads flash config, configures TIM1 PWM, initializes ADC, calibrates current sensor, enables SysTick

### Source Files

| File | Purpose |
|---|---|
| `src/main.c` | Application logic: UART, protocol parser, PID controller, ADC, flash storage |
| `src/startup.c` | Vector table, `Reset_Handler`, weak IRQ symbol definitions |
| `src/hal_adc.c` | MindMotion HAL — ADC driver |
| `src/hal_gpio.c` | MindMotion HAL — GPIO driver |
| `src/hal_misc.c` | MindMotion HAL — NVIC utilities |
| `src/hal_rcc.c` | MindMotion HAL — Clock configuration |
| `src/hal_tim.c` | MindMotion HAL — Timer driver |
| `src/hal_usart.c` | MindMotion HAL — USART driver |
| `custom.ld` | Custom linker script (2 KB RAM, 16 KB Flash) |

---

## 📡 Communication Protocol

μDrive uses a **half-duplex single-wire UART** bus on **PA12** (open-drain) at **250000 baud, 8N1**. Multiple servos can share the same bus using unique IDs.

### Packet Format

All communication uses a binary packet format:

```text
┌──────┬──────┬──────┬────────┬─────────────┬──────────┬──────────┐
│ 0xFF │ 0xFF │  ID  │ Length │ Instruction │ Params…  │ Checksum │
└──────┴──────┴──────┴────────┴─────────────┴──────────┴──────────┘
```

| Field | Size | Description |
|---|---|---|
| Header | 2 bytes | Always `0xFF 0xFF` |
| ID | 1 byte | Target servo ID (`0`–`127`), or `0xFE` for broadcast |
| Length | 1 byte | Number of bytes following: `Instruction + Params + Checksum` |
| Instruction | 1 byte | Command opcode (see below) |
| Params | 0–N bytes | Instruction-specific payload |
| Checksum | 1 byte | `~(ID + Length + Instruction + Params) & 0xFF` |

> [!NOTE]
> Broadcast ID `0xFE` sends a command to all servos on the bus. No reply is generated for broadcast packets.

### Instructions

| Opcode | Name | Direction | Description |
|---|---|---|---|
| `0x01` | CONTROL | Master → Servo | Move to target angle with optional velocity and current limit |
| `0x02` | CONFIG | Master → Servo | Update configuration fields (with bitmask for partial updates) |
| `0x03` | POLL | Master → Servo | Request current status |
| `0x04` | CLEAR_ERROR | Master → Servo | Clear overcurrent faults and reset PID state |
| `0x05` | READ_CONFIG | Master → Servo | Read current flash configuration |

---

### 0x01 — CONTROL

Moves the servo to a target angle with optional velocity and current limit overrides.

**Parameters (4 or 6 bytes):**

| Byte | Field | Type | Description |
|---|---|---|---|
| 0–1 | `angle` | uint16 LE | Target angle in degrees |
| 2–3 | `velocity` | uint16 LE | Velocity in deg/s (`0` = use config default) |
| 4–5 | `current` | uint16 LE | Current limit in mA (`0` = use config default). *Optional.* |

**Behavior:**
- Angle is clamped to `[min_angle, max_angle]` from the config
- Arms the motor on the first valid CONTROL packet
- Ignored if an overcurrent fault is active
- No status reply is sent (for maximum control loop throughput)

---

### 0x02 — CONFIG

Updates one or more configuration fields. A **bitmask** in the first parameter byte selects which fields to write. Unselected fields remain unchanged.

**Parameters (up to 26 bytes):**

| Byte | Field | Bitmask Bit | Description |
|---|---|---|---|
| 0 | `update_mask` | — | Bitmask selecting which fields to update |
| 1 | `id_and_dir` | Bit 0 | Lower 7 bits = `servo_id`, MSB = `direction_invert` |
| 2–3 | `min_angle` | Bit 1 | Minimum angle limit (uint16 LE) |
| 4–5 | `max_angle` | Bit 1 | Maximum angle limit (uint16 LE) |
| 6–7 | `max_velocity` | Bit 2 | Default velocity, deg/s (uint16 LE) |
| 8–9 | `current_limit` | Bit 3 | Overcurrent threshold, mA (uint16 LE) |
| 10–13 | `kp_q16` | Bit 4 | Proportional gain, Q16 (int32 LE) |
| 14–17 | `ki_q16` | Bit 4 | Integral gain, Q16 (int32 LE) |
| 18–21 | `kd_q16` | Bit 4 | Derivative gain, Q16 (int32 LE) |
| 22–23 | `zero_adc` | Bit 5 | ADC value at 0° (int16 LE) |
| 24–25 | `adc_per_360` | Bit 5 | ADC ticks per 360° rotation (int16 LE) |

**Special flag — Bit 6 (Volatile):**
- If Bit 6 of `update_mask` is **set**, the config update is **RAM-only** (not persisted to flash).
- If Bit 6 is **clear**, the config is written to flash.

**Reply:** Status packet (11 bytes) echoing instruction `0x02`.

---

### 0x03 — POLL

Requests the servo's current status. No parameters.

**Reply:** Status packet (11 bytes).

---

### 0x04 — CLEAR_ERROR

Clears an overcurrent fault and resets the PID state.

**Parameters (1 byte):**

| Byte | Value | Description |
|---|---|---|
| 0 | `1` | Clear error flag, reset PID, disarm motor |

**Behavior:**
- Clears `overcurrent_fault` and `overcurrent_ms`
- Resets PID integral and derivative state
- Disarms motor (allows manual shaft positioning)
- Sets the target and ghost angles to the current physical angle

---

### 0x05 — READ_CONFIG

Reads the full configuration from the servo.

**Reply:** Config packet (36 bytes) — header + full `ServoConfig` struct as parameters.

---

### Status Reply Packet (11 bytes)

Sent in response to POLL or CONFIG commands:

```text
┌──────┬──────┬──────┬──────┬─────────────┬───────────────────────────────────┬──────────┐
│ 0xFF │ 0xFF │  ID  │ 0x07 │ Instruction │  angle(2) current(2) flags(1)    │ Checksum │
└──────┴──────┴──────┴──────┴─────────────┴───────────────────────────────────┴──────────┘
```

| Param Bytes | Field | Type | Description |
|---|---|---|---|
| 0–1 | `current_angle` | uint16 LE | Current servo angle in degrees |
| 2–3 | `current_ma` | uint16 LE | Current motor draw in milliamps |
| 4 | `flags` | uint8 | Status flags (see below) |

**Status Flags:**

| Bit | Name | Description |
|---|---|---|
| 0 | `MOVING` | Servo is actively tracking a target |
| 1 | `OVERCURRENT` | Overcurrent fault is active |
| 2 | `HOLDING` | Admittance yield mode is active (compliant holding) |

### Config Reply Packet (36 bytes)

Sent in response to READ_CONFIG:

```text
┌──────┬──────┬──────┬──────┬──────┬──────────────────────────────┬──────────┐
│ 0xFF │ 0xFF │  ID  │  32  │ 0x05 │  ServoConfig struct (30 B)   │ Checksum │
└──────┴──────┴──────┴──────┴──────┴──────────────────────────────┴──────────┘
```

---

## 🎯 PID Control System

### Control Loop Architecture

μDrive uses a **position PID controller with velocity trajectory profiling** (ghost target). The entire control loop runs inside the `SysTick_Handler` at a fixed 1 ms interval, guaranteeing deterministic timing even if the main loop is busy sending UART replies.

```mermaid
graph LR
    TA["<span style='color:#000'>🎯 Target Angle</span>"] --> Traj["<span style='color:#000'>📈 Trajectory Ramping</span>"]
    Traj -->|"ghost_angle_q8"| PID["<span style='color:#000'>🎛️ PID Controller</span>"]
    CA["<span style='color:#000'>🔍 Current Angle (q8)<br>(ADC + filter)</span>"] --> PID
    PID -->|"PWM duty"| TIM["<span style='color:#000'>⚡ PWM Duty<br>(TIM1 CH2/CH3)</span>"]
    PID --> OCP["<span style='color:#000'>🛡️ Overcurrent Protection</span>"]

    %% Styling
    style TA fill:#e3f2fd,stroke:#1565c0,stroke-width:2px;
    style Traj fill:#f3e5f5,stroke:#7b1fa2,stroke-width:2px;
    style PID fill:#fff3e0,stroke:#e65100,stroke-width:2px;
    style CA fill:#efebe9,stroke:#4e342e,stroke-width:2px;
    style TIM fill:#e8f5e9,stroke:#2e7d32,stroke-width:2px;
    style OCP fill:#ffebee,stroke:#c62828,stroke-width:2px;
```

### Ghost Target (Velocity Profiling)

The **ghost target** (`ghost_angle_q8`) is an intermediate angle that ramps toward the final `target_angle` at the configured velocity. The PID controller tracks the ghost target — not the final target — producing smooth acceleration and deceleration.

```
Step per ms = (active_velocity × 256) / 1000    (Q8 format)
```

If `active_velocity` is `0`, the ghost target snaps instantly to the final target.

### PID Computation

All PID math uses **Q8 fixed-point** for angles and **Q16 fixed-point** for gains, combined through **Q24 intermediate precision** using 64-bit multiply:

```c
p_term = Kp_q16 × error_q8              // Q24
i_term = Ki_scaled_q16 × integral_q8     // Q24
d_term = Kd_q16 × derivative_q8 × 1000  // Q24 (scaled for 1ms timestep)

pid_output = (p_term + i_term + d_term) >> 24
```

### Key Parameters

| Parameter | Value | Description |
|---|---|---|
| Loop interval | 1 ms | SysTick-driven, deterministic |
| Deadband | 1° (256 in Q8) | Error below this → motor brakes / coasts |
| Integral windup limit | 25,600,000 (Q8) | ≈ 100 degree-seconds |
| ADC filter alpha | 0.10 (26/256) | EMA low-pass on potentiometer reading |
| Current filter alpha | 0.15 (38/256) | EMA low-pass on current measurement |

### Overcurrent Protection

μDrive implements a two-tier current protection system:

| Tier | Threshold | Behavior |
|---|---|---|
| **Soft limit** (admittance yield) | `current_limit` (configurable, default 1000 mA) | Dynamically clamps PWM duty cycle. Allows the motor to yield compliantly. |
| **Hard fault** | 2000 mA sustained for ≥ 50 ms | Latching fault — motor is disabled. Must be cleared with `CLEAR_ERROR` command. |

#### Soft Current Limiting (Admittance Yield Loop)

To prevent motor/driver overheating and enable compliant backdriving (force limiting), the controller implements a dynamic current-clamping algorithm in the 1 ms control loop:

1. **Dynamic PWM Clamping**:
   - Every 1 ms, if the filtered current `current_ma` exceeds `active_current_limit`, the allowable PWM duty cycle limit (`pwm_clamp`) is decremented:
     $$\text{pwm\_clamp} \leftarrow \max(0, \text{pwm\_clamp} - 20)$$
     This triggers the `yield_active` compliance flag.
   - If the current is below the threshold, the clamp slowly recovers toward the full timer period (`arr_period`):
     $$\text{pwm\_clamp} \leftarrow \min(\text{arr\_period}, \text{pwm\_clamp} + 5)$$
     Once `pwm_clamp` reaches `arr_period`, `yield_active` is cleared.
   - The PID output is then clamped to $[-\text{pwm\_clamp}, \text{pwm\_clamp}]$.

2. **Decay Mode Transition (Coast vs. Brake)**:
   - **Stiff Mode (`yield_active` is false)**: The driver operates in **slow decay (brake mode)**, where inactive outputs are held high. This provides maximum holding stiffness and positioning precision.
   - **Yield/Compliance Mode (`yield_active` is true)**: The driver switches to **fast decay (coast mode)**, pulsing only one phase while leaving the other at 0. This reduces braking torque and allows the shaft to yield/backdrive smoothly under external load.

### Motor Arming

The motor is **disarmed at boot**. It will not drive the motor until the first valid `CONTROL` packet is received. This prevents unexpected motion on power-up.

### Auto-Zero Calibration

At startup, the firmware reads 16 samples from the current sense ADC (with the motor off) and averages them to establish a zero-current baseline offset. This compensates for component tolerances in the INA180A2 and shunt resistor.

---

## 💾 Flash Configuration

Configuration is stored in **Flash page 15** (the last 1 KB page of the 16 KB flash), starting at address `0x08003C00`. A magic word (`0xDEADBEEF`) validates stored data.

### ServoConfig Structure (30 bytes, packed)

| Offset | Field | Type | Default | Description |
|---|---|---|---|---|
| 0 | `servo_id` | uint8 | `0` | Bus address (0–127) |
| 1 | `direction_invert` | uint8 | `0` | Motor direction (0 = normal, 1 = inverted) |
| 2 | `min_angle` | uint16 | `0` | Minimum angle limit (degrees) |
| 4 | `max_angle` | uint16 | `180` | Maximum angle limit (degrees) |
| 6 | `max_velocity` | uint16 | `180` | Default velocity (deg/s) |
| 8 | `current_limit` | uint16 | `1000` | Overcurrent threshold (mA) |
| 10 | `kp_q16` | int32 | `6553600` (= 100.0) | Proportional gain (Q16 fixed-point) |
| 14 | `ki_q16` | int32 | `3276` (= 0.05) | Integral gain (Q16 fixed-point) |
| 18 | `kd_q16` | int32 | `524288` (= 8.0) | Derivative gain (Q16 fixed-point) |
| 22 | `zero_adc` | int16 | `0` | Raw ADC value at 0° |
| 24 | `adc_per_360` | int16 | `6600` | ADC ticks per full 360° rotation |
| 26 | `magic` | uint32 | `0xDEADBEEF` | Validity marker |

> [!TIP]
> **Q16 conversion:** To convert a floating-point gain to Q16, multiply by 65536. For example, `Kp = 100.0` → `100.0 × 65536 = 6553600`.

### Flash Write Process

1. Motor PWM outputs are forced to 0 for safety
2. Flash page 15 is erased
3. Config struct is written as half-words (16-bit aligned)
4. Flash is re-locked

> [!CAUTION]
> Flash writes temporarily disable motor output. Avoid sending CONFIG commands during motion-critical operations unless using the volatile (Bit 6) flag.

---

## 🔨 Build & Flash

### Toolchain

| Tool | Purpose |
|---|---|
| **PlatformIO** | Build system (VS Code extension) |
| **GCC ARM** | Compiler (`arm-none-eabi-gcc`, via PlatformIO) |
| **pyocd** | Flash programmer |
| **Picoprobe / CMSIS-DAP** | SWD debug probe (Raspberry Pi Pico) |

### PlatformIO Configuration

The project repurposes the `ststm32` platform with the `disco_f030r8` board definition, overriding the memory layout to match the MM32G0001:

```ini
[env:disco_f030r8]
platform = ststm32
board = disco_f030r8
board_build.cpu = cortex-m0

upload_protocol = custom
upload_command = pyocd flash --pack "MindMotion.MM32G0001_DFP.1.0.1.pack" --target mm32g0001a1tc $SOURCE

board_upload.maximum_size = 16384
board_upload.maximum_ram_size = 2048
board_build.ldscript = custom.ld

build_flags =
  -D USE_STDPERIPH_DRIVER
```

### Build

```bash
# Using PlatformIO CLI
pio run

# Or use the PlatformIO "Build" button (checkmark icon) in VS Code
```

### Flash

Connect a Picoprobe (Raspberry Pi Pico with debugprobe firmware) via SWD:

| Pico Pin | μDrive Pad |
|---|---|
| 3V3 | 3.3V |
| GND | GND |
| GP2 | SWCLK (**C**) |
| GP3 | SWDIO (**D**) |

Then flash:

```bash
# Using PlatformIO (recommended)
pio run --target upload

# Or manually with pyocd
pyocd flash --pack "MindMotion.MM32G0001_DFP.1.0.1.pack" --target mm32g0001a1tc firmware.bin
```

> [!IMPORTANT]
> **Windows users:** If pyocd fails to detect the Picoprobe, use [Zadig](https://zadig.akeo.ie/) to replace the default driver with **WinUSB** for the "Picoprobe CMSIS-DAP" device.

The MindMotion DFP pack file (`MindMotion.MM32G0001_DFP.1.0.1.pack`) is included in the repository root.

### Custom Linker Script

The `custom.ld` file defines the memory layout for the MM32G0001:

```
MEMORY
{
  RAM    (xrw) : ORIGIN = 0x20000000, LENGTH = 2K
  FLASH  (rx)  : ORIGIN = 0x08000000, LENGTH = 16K
}
```

Stack size: 512 bytes. No heap is allocated.

---

## 📚 HAL Drivers

The project uses MindMotion's Standard Peripheral Library (HAL) for hardware abstraction. The following HAL modules are compiled into the firmware:

| Module | File | Functionality |
|---|---|---|
| ADC | `hal_adc.c` / `hal_adc.h` | 12-bit ADC for potentiometer and current sensing |
| GPIO | `hal_gpio.c` / `hal_gpio.h` | Pin configuration, alternate functions |
| MISC | `hal_misc.c` / `hal_misc.h` | NVIC interrupt priority and enable |
| RCC | `hal_rcc.c` / `hal_rcc.h` | Peripheral clock gating |
| TIM | `hal_tim.c` / `hal_tim.h` | TIM1 PWM output for H-bridge motor control |
| USART | `hal_usart.c` / `hal_usart.h` | Half-duplex single-wire UART |

---

## 🔄 Interrupt Map

| IRQ | Handler | Priority | Purpose |
|---|---|---|---|
| SysTick | `SysTick_Handler` | 0 | 1 ms PID loop, trajectory ramping, overcurrent protection |
| USART1 | `USART1_IRQHandler` | 1 | RX interrupt-driven binary packet parser |
| TIM1_CC | `TIM1_CC_IRQHandler` | 2 | Midpoint-synchronized current sample acquisition |

The PID loop runs entirely within the SysTick ISR (highest priority), ensuring deterministic 1 ms timing regardless of main-loop activity. The UART packet parser is fully interrupt-driven using a state machine, and the motor current is sampled asynchronously at the PWM midpoint using `TIM1` Channel 1 (CC1) to eliminate CPU busy-waiting.

---

## 📐 Fixed-Point Arithmetic Reference

Since the Cortex-M0 has no floating-point unit, all math uses integer fixed-point formats:

| Format | Fractional Bits | Resolution | Usage |
|---|---|---|---|
| **Q8** | 8 | 1/256 ≈ 0.004 | Angles, PID error, integral, derivative |
| **Q16** | 16 | 1/65536 ≈ 0.000015 | PID gains (`Kp`, `Ki`, `Kd`) |
| **Q24** | 24 | — | Intermediate PID computation (64-bit) |

**Conversion formulas:**
```
float → Q16:  value_q16 = (int32_t)(float_value × 65536)
Q16 → float:  float_value = value_q16 / 65536.0
float → Q8:   value_q8  = (int32_t)(float_value × 256)
Q8 → float:   float_value = value_q8 / 256.0
```

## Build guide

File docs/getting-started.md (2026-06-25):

# 🚀 Getting Started with μDrive (Microdrive)

A step-by-step guide to flashing the servo board, wiring up a master controller, and commanding your first microdrive.

---

## 📋 Prerequisites

### Hardware

| Item | Notes |
|---|---|
| **Raspberry Pi Pico** | Used first as a programmer, then re-flashed as the master MCU |
| **μDrive board** | The MM32G0001-based servo controller PCB |
| **DC motor with potentiometer** | Any brushed DC motor within the driver limits (e.g., ≤ 7.5V / 1.5A for the MG996 board, or ≤ 18V / 5A for the Servo Board) |
| **External power supply** | Suitable voltage for your motor and board (do **not** power the motor from the microcontroller's 3V3/5V pin) |
| **Jumper wires** | At least 4 for SWD programming + 3 for the servo bus |
| **Pull-up resistor** | 1 kΩ – 10 kΩ (4.7 kΩ recommended) for the single-wire data bus |
| **USB cable** | Micro-USB or USB-C depending on your Pico variant |

### Software

| Tool | Install |
|---|---|
| **VS Code** | [code.visualstudio.com](https://code.visualstudio.com/) |
| **PlatformIO extension** | Install from the VS Code Extensions marketplace |
| **Python 3.x** | [python.org](https://python.org/) |
| **pyocd** | `pip install pyocd` |
| **Node.js + npm** | Required only for the WebGUI (optional) |

---

## Step 1 — Flash the Servo Board

The μDrive board runs an MM32G0001 microcontroller. Since dedicated programmers for this chip are expensive and hard to find, we use a **$4 Raspberry Pi Pico** as a CMSIS-DAP debug probe instead.

> [!TIP]
> Once the servo board is flashed, you can wipe the Pico and reuse it as the master MicroPython controller — so you only need one Pico for the whole project.

### 1.1 Turn the Pico into a Programmer

1. Download `debugprobe_on_pico.uf2` from the [Raspberry Pi Debug Probe releases](https://github.com/raspberrypi/debugprobe/releases).
2. Hold the **BOOTSEL** button on the Pico while plugging it into USB.
3. Drag-and-drop the `.uf2` file onto the `RPI-RP2` drive that appears.
4. The Pico reboots as a **Picoprobe (CMSIS-DAP)** debugger.

### 1.2 Wire the Pico to the μDrive Board

Connect these **4 wires** from the Pico to the SWD programming header on the μDrive board:

| Pico Pin | μDrive Pin | Function |
|---|---|---|
| **3V3** | **3.3V** | Power to the target |
| **GND** | **GND** | Common ground |
| **GP2** | **SWCLK** (labeled **C**) | Serial Wire Clock |
| **GP3** | **SWDIO** (labeled **D**) | Serial Wire Data |

```mermaid
graph LR
    subgraph Probe["Raspberry Pi Pico (Picoprobe)"]
        3V3["<span style='color:#000'>3V3 (pin 36)</span>"]
        GND1["<span style='color:#000'>GND (pin 38)</span>"]
        GP2["<span style='color:#000'>GP2 (pin 4)</span>"]
        GP3["<span style='color:#000'>GP3 (pin 5)</span>"]
    end
    subgraph Servo["μDrive Board"]
        V33["<span style='color:#000'>3.3V</span>"]
        GND2["<span style='color:#000'>GND</span>"]
        CLK["<span style='color:#000'>C (SWCLK)</span>"]
        DIO["<span style='color:#000'>D (SWDIO)</span>"]
    end
    3V3 --- V33
    GND1 --- GND2
    GP2 --- CLK
    GP3 --- DIO

    style 3V3 fill:#e1f5fe,stroke:#01579b,stroke-width:2px;
    style GND1 fill:#efebe9,stroke:#3e2723,stroke-width:2px;
    style GP2 fill:#e1f5fe,stroke:#01579b,stroke-width:2px;
    style GP3 fill:#e1f5fe,stroke:#01579b,stroke-width:2px;

    style V33 fill:#fff3e0,stroke:#e65100,stroke-width:2px;
    style GND2 fill:#efebe9,stroke:#3e2723,stroke-width:2px;
    style CLK fill:#fff3e0,stroke:#e65100,stroke-width:2px;
    style DIO fill:#fff3e0,stroke:#e65100,stroke-width:2px;
```

### 1.3 Install the Flashing Tools

```bash
pip install pyocd
```

> [!WARNING]
> **Windows users:** If `pyocd` cannot detect your probe, Windows likely assigned the wrong default driver. Download the free [Zadig tool](https://zadig.akeo.ie/), select **"Picoprobe CMSIS-DAP"** from the dropdown, and replace the driver with **WinUSB**.

### 1.4 Open the Project and Flash

1. Clone the Microdrive repository (or open the project folder).
2. Open the `Microdrive` folder in **VS Code**.
3. PlatformIO will automatically detect the project (see `platformio.ini`).
4. Click the **Upload** button (the `→` arrow in the PlatformIO toolbar at the bottom of the screen).

PlatformIO compiles the firmware and invokes `pyocd` to flash the MM32G0001 automatically:

```
pyocd flash --pack "MindMotion.MM32G0001_DFP.1.0.1.pack" --target mm32g0001a1tc <firmware.bin>
```

> [!NOTE]
> The project uses a custom linker script (`custom.ld`) that sets RAM to 2 KB and Flash to 16 KB — the actual limits of the MM32G0001. The default STM32F030R8 board definition in PlatformIO assumes 8 KB of RAM, which would cause a Hard Fault on boot.

---

## Step 2 — Set Up the Master MCU

Once the servo board is flashed, it listens for commands over a half-duplex UART bus. You need a **master microcontroller** to send those commands.

### 2.1 Flash MicroPython onto the Pico

1. Download the latest MicroPython `.uf2` firmware for the Pico from [micropython.org](https://micropython.org/download/RPI_PICO/).
2. Hold **BOOTSEL**, plug in the Pico, and drag-and-drop the `.uf2` file.
3. The Pico reboots as a MicroPython device.

### 2.2 Copy the Driver

Copy `micropython/microdrive.py` from this repository onto the Pico's filesystem (using Thonny, `mpremote`, or `ampy`).

### 2.3 Wire the Servo Bus

The servo firmware uses **half-duplex single-wire UART** on PA12 (open-drain) at **250,000 baud, 8N1**.

#### Minimal Single-Wire Wiring

On boards that do not natively support open-drain half-duplex UART on a single pin (like the Raspberry Pi Pico / RP2040), connect the RX pin directly to the servo data line, and connect the TX pin to the RX pin/bus through a **1kΩ isolation resistor**. No external pull-up is needed since the μDrive PCB already has an onboard 10kΩ pull-up on the data bus.

```mermaid
graph LR
    subgraph MCU["MicroPython MCU (Pico)"]
        TX["<span style='color:#000'>GP4 (TX)</span>"]
        RX["<span style='color:#000'>GP5 (RX)</span>"]
        GND1["<span style='color:#000'>GND</span>"]
    end
    subgraph Servo["μDrive Servo Board"]
        Data["<span style='color:#000'>Data Bus (PA12)<br>(Onboard 10kΩ pull-up)</span>"]
        GND2["<span style='color:#000'>GND</span>"]
        VPlus["<span style='color:#000'>Servo V+</span>"]
    end
    subgraph PSU["External Power Supply (PSU)"]
        GND3["<span style='color:#000'>GND</span>"]
        VOut["<span style='color:#000'>V+</span>"]
    end
    Res["<span style='color:#000'>1kΩ  Resistor</span>"]

    TX --- Res
    RX --- Res
    RX --- Data
    GND1 --- GND2
    GND2 --- GND3
    VPlus --- VOut

    style TX fill:#e1f5fe,stroke:#01579b,stroke-width:2px;
    style RX fill:#e1f5fe,stroke:#01579b,stroke-width:2px;
    style Res fill:#f3e5f5,stroke:#7b1fa2,stroke-width:2px;
    style Data fill:#fff3e0,stroke:#e65100,stroke-width:2px;
    style GND1 fill:#efebe9,stroke:#3e2723,stroke-width:2px;
    style GND2 fill:#efebe9,stroke:#3e2723,stroke-width:2px;
    style VOut fill:#ffebee,stroke:#c62828,stroke-width:2px;
    style GND3 fill:#efebe9,stroke:#3e2723,stroke-width:2px;
    style VPlus fill:#ffebee,stroke:#c62828,stroke-width:2px;
```

> [!IMPORTANT]
> - A **1kΩ isolation resistor** is required between the TX pin (GP4) and the RX/Data Line.
> - The μDrive PCB already has an onboard **10kΩ pull-up resistor** on the Data Bus, so no external pull-up is required.
> - Ensure a **common ground** exists between the external power supply, the Pico, and the μDrive board.

### 2.4 Basic Usage Example

```python
from machine import UART, Pin
from microdrive import ServoBus

# Initialize UART at 250000 baud
uart = UART(1, baudrate=250000, tx=Pin(4), rx=Pin(5))
bus  = ServoBus(uart)

# Get a handle to the servo at ID 0 (factory default)
servo = bus.servo(0)

# Move to 90 degrees
servo.move(90)

# Check status
status = servo.poll()
if status:
    print(f"Angle: {status.angle}°")
    print(f"Current: {status.current_ma} mA")
    print(f"Moving: {status.is_moving}")
```

### 2.5 Scan the Bus

Discover all connected servos:

```python
found = bus.scan(id_range=range(0, 128))
for sid, status in found:
    print(f"Servo {sid}: {status.angle}°, {status.current_ma} mA")
```

> [!NOTE]
> Scanning is slow — each non-responding ID waits for the full reply timeout (default 5 ms). Narrow the `id_range` if you know which IDs to expect.

---

## Step 3 — Launch the WebGUI (Optional)

The project includes a **Svelte-based web dashboard** that connects to your servo network through the browser's Web Serial API.

```

### 3.1 Run the Serial Proxy

The master Pico must run the serial bridge script that translates JSON commands from the browser into servo bus packets:

1. Copy both `microdrive.py` **and** `serial_proxy.py` onto the Pico.
2. The proxy starts automatically on boot (or run it from the REPL).
3. Connect the Pico to your PC via USB.

### 3.2 Start the Web Dev Server

```bash
cd gui/
npm install
npm run dev
```

### 3.3 Connect from the Browser

1. Open the provided `localhost` link in **Chrome** or **Edge** (must support Web Serial API).
2. Click the connect button and select the Pico's serial port.
3. You can now scan, move, tune PID, and configure servos directly from the dashboard.

> [!WARNING]
> The Web Serial API is **not** supported in Firefox or Safari. Use Chrome or Edge.

---

## ⚡ Important Notes

| Topic | Detail |
|---|---|
| **Baud rate** | The servo bus runs at **250,000 baud**, 8N1 |
| **Default servo ID** | Factory-fresh servos start at **ID 0** |
| **Safety feature** | The motor does **not** start moving until the first `CONTROL` command is received — the H-bridge stays off until then |
| **Bus wire mode** | The UART uses **PA12 in open-drain mode** for bus sharing; a pull-up resistor is mandatory |
| **Motor power** | Always use an **external power supply** for the motor — never power it from the microcontroller's USB rail |
| **Reply timeout** | Default is **5 ms** — the servo firmware replies in ~2.7 ms on average |

---

## 🔗 Next Steps

- Read the [API Reference](api-reference.md) for the full MicroPython driver documentation.
- Run `micropython/calibrate_pid.py` to auto-tune PID gains for your motor.
- Run `micropython/hard_angle_set.py` to calibrate the potentiometer's physical limits.
- Check the [Troubleshooting Log](../docs/troubleshoot.md) if the chip won't flash or respond.

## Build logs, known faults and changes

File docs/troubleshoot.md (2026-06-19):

# 🛠️ Troubleshooting Guide

Common problems and their fixes when working with μDrive.

---

## 1. Flashing & Programming

### pyocd can't find the probe

```
No USB probes found
```

**Fix (Windows):** Windows assigns the wrong driver by default. Use [Zadig](https://zadig.akeo.ie/):

1. Options → List All Devices
2. Select **Picoprobe CMSIS-DAP**
3. Replace driver with **WinUSB**
4. Re-run `pyocd list` — the probe should now appear

If the probe still doesn't show, re-flash Picoprobe firmware: hold `BOOTSEL`, plug in the Pico, drag-and-drop `debugprobe_on_pico.uf2`.

---

### pyocd finds probe but can't connect to MM32G0001

```
Target connection failed: CMSIS-DAP transfer timed out
```

**Check wiring** — the two SWD wires get swapped constantly:

| Pico Pin | μDrive Pad | Function |
|---|---|---|
| GP2 | **C** | SWCLK |
| GP3 | **D** | SWDIO |
| GND | GND | Ground |
| 3V3 | 3.3V | Power |

Also:
- Measure the **3.3V** test pad on the μDrive board. Should read `3.15V – 3.45V`. If it's 0V, the LDO may be dead or no power is reaching the board.
- Keep SWD wires **short** (under 15 cm). Long dupont wires cause signal integrity issues. If you must use long wires, slow down the clock:
  ```
  pyocd flash -f 500000 --pack "MindMotion.MM32G0001_DFP.1.0.1.pack" --target mm32g0001a1tc firmware.bin
  ```

---

## 2. Chip Boots but Nothing Happens

### Firmware flashes fine but MCU is completely dead

This is almost always the **linker script** problem. The project borrows PlatformIO's `disco_f030r8` board definition (STM32F030R8), which assumes **8 KB RAM**. The MM32G0001 only has **2 KB**.

What happens: the startup code sets the initial stack pointer to `0x20002000` (top of 8K). The MM32's physical RAM ends at `0x20000800`. First stack write hits non-existent memory → instant Hard Fault before `main()` even runs.

**Fix:** Make sure `platformio.ini` points to the custom linker script:

```ini
board_build.ldscript = custom.ld
```

Verify `custom.ld` has the correct memory sizes:

```ld
MEMORY
{
  FLASH (rx)  : ORIGIN = 0x08000000, LENGTH = 16K
  RAM (xrw)   : ORIGIN = 0x20000000, LENGTH = 2K
}
```

You can double-check the compiled binary:

```bash
arm-none-eabi-readelf -s .pio/build/disco_f030r8/firmware.elf | grep _estack
```

`_estack` must be `0x20000800`, **not** `0x20002000`.

---

## 3. UART / Serial Communication

### Getting garbage bytes or continuous 0x00 (NUL) on serial monitor

Two common causes:

**1. Wrong pin.** On the TSSOP-20 package, USART1 TX/RX is on **PA12 = Pin 17**. It's easy to accidentally wire to the wrong physical pin. Double-check against the [pinout diagram](../mm32g0001ait_pinout.png).

**2. Baud rate divisor miscalculation.** The USART BRR register expects the divisor to include the 16× oversampling factor:

```
USARTDIV = SystemClock / (BaudRate × 16)
```

If you forget to divide by 16, the actual baud rate will be 16× slower than expected. At 9600 target, you'd actually get ~600 baud — the receiver sees nothing but framing errors and NUL bytes.

For the production firmware (48 MHz clock, 250000 baud), the HAL handles this automatically via `USART_Init()`. If you're doing manual register config, the divisor is:

```
48000000 / (250000 × 16) = 12
```

---

### Master sends commands but gets no replies

**Check the isolation resistor.** The bus is half-duplex on a single wire. The Master's TX pin needs a **1 kΩ resistor** in series before joining the shared data line, otherwise TX drives the bus and blocks the servo's replies.

```
Pico GP4 (TX) ──[1kΩ]──┐
                        ├──── μDrive PA12 (Data Bus)
Pico GP5 (RX) ──────────┘
```

**Check common ground.** The MCU GND and the μDrive board GND must be directly connected. Floating ground = the receiver can't distinguish high from low.

**Check servo ID.** Factory default ID is `0`. If your code is sending to ID `1`, the servo silently ignores it. Test with a broadcast:

```python
servo = bus.servo(0)   # make sure this matches actual ID
status = servo.poll()  # should return a ServoStatus object
```

If you're unsure what ID is stored in flash, use READ_CONFIG (`0x05`) with broadcast ID `0xFE` — but note that broadcast packets don't generate replies. You'll need to address at least one known ID, or re-flash the firmware to reset config to defaults.

**Check baud rate.** The firmware runs at **250000** baud, not 9600 or 115200. Make sure your master UART matches:

```python
uart = UART(1, baudrate=250000, tx=Pin(4), rx=Pin(5))
```

---

### Reply timeout (5ms default) is too aggressive

The `_REPLY_TIMEOUT_MS` in `microdrive.py` is set to 5 ms. The servo firmware deliberately delays its reply by 2 ms (`reply_trigger_time_ms = millis() + 2`) to avoid bus collisions. On slower master MCUs or with bus capacitance, 5 ms may be tight.

If you're getting intermittent `None` returns from `poll()`, try increasing the timeout:

```python
bus = ServoBus(uart, dir_pin=Pin(4, Pin.OUT), timeout_ms=10)
```

---

## 4. Motor Control

### Motor spins full speed in one direction and won't stop (runaway)

This is **positive feedback** — the PID loop is pushing the motor the wrong way, which increases the error, which pushes harder. The motor will spin until overcurrent protection trips (2000 mA sustained for 50 ms).

**Fix — toggle direction:** Either swap the two motor wires physically, or set the `direction_invert` flag in software:

```python
servo.configure(direction_invert=True)
```

If the motor doesn't have a potentiometer connected (or it's disconnected), the ADC reads a floating/random value and the PID has no valid feedback — same runaway symptom. Verify the pot wiper is connected to the **SDA** test pad.

---

### Motor vibrates/oscillates instead of holding position

The PID gains are too aggressive for your motor and gearbox combination.

**Quick fix — conservative gains:**

```python
servo.configure(kp=1.0, ki=0.0, kd=0.0)
```

Then tune up:
1. Increase `kp` until the motor just barely starts to oscillate on a step input
2. Add `kd` to damp the oscillation
3. Only add `ki` if there's persistent steady-state error (motor stops a few degrees short of target). Keep it very small — large `ki` causes integral windup

The firmware defaults are `kp=100.0`, `ki=0.05`, `kd=8.0` — these were tuned for a specific MG996R motor and may be wildly wrong for your setup.

---

### Motor doesn't move at all after sending CONTROL packets

The motor is **not armed** until the first valid CONTROL packet arrives. But if there's an active overcurrent fault, CONTROL packets are silently ignored.

Check for faults:

```python
status = servo.poll()
print(status)  # look for OVERCURRENT flag
```

If overcurrent is active, clear it first:

```python
servo.clear_error()
servo.move(90)  # now this will work
```

The overcurrent fault triggers when current exceeds **2000 mA** for **50 consecutive milliseconds**. This is a hard safety limit defined by `HARD_OCP_LIMIT_MA` in the firmware. Common triggers: stalled motor, mechanical binding, or a short in the motor wiring.

---

### Motor overshoots badly, then slowly creeps to position

High overshoot with slow settling = `kp` too high and `kd` too low. The proportional term drives the motor past the target, and there isn't enough derivative damping to slow it down as it approaches.

Also check the **velocity profile**. The firmware uses a "ghost target" trajectory ramp — the internal target moves toward the commanded angle at `active_velocity` deg/s. If velocity is set very high (or 0, which means instant), the PID sees a huge instantaneous step and overshoots.

```python
# Move with a gentle velocity ramp
servo.move(180, velocity=90)  # 90 deg/s instead of instant
```

---

## 5. Power & EMI

### MCU crashes or resets when motor starts / stalls / reverses

This is the most common hardware issue. DC motors generate massive current spikes and back-EMF when starting, stalling, or changing direction. This can:

1. **Sag the power rail** below the LDO's dropout voltage → MCU brown-out resets
2. **Inject noise** into the UART or SWD lines → corrupted packets or MCU lockup

**Fixes:**
- **Never** power the motor from USB or the Pico's 3.3V/5V pins. Always use a separate external supply rated for the motor's stall current.
- Add a **100μF – 470μF electrolytic cap** across the motor power input (V+ and GND on the μDrive board), as close to the board as possible.
- Solder a **100nF ceramic cap** directly across the motor terminals to suppress brush arcing.
- Verify that bypass caps C2 and C3 (100nF) are populated near the MCU.

**Diagnosis:** Probe the 3.3V test pad with a scope while stalling the motor. If the 3.3V rail dips below ~2.7V, the MCU is brown-out resetting.

---

### Current readings are wrong or always zero

The current sensor (INA180A2 + 0.01Ω shunt on PA2) is calibrated at boot via `calibrate_current_sensor()`. It takes 16 ADC samples with the motor idle to establish a zero-current baseline.

If you're seeing wrong readings:
- Make sure the motor is **not running** during the first ~20ms after power-on (the calibration window)
- If R1 (the 0.01Ω sense resistor) is not populated or cracked, current will always read 0
- The calibration slope (`1.465 mA/count`) was derived from a specific dummy-load bench test. Your board's component tolerances may differ — if readings are consistently off by a fixed percentage, the slope factor in `update_current_ma()` may need adjustment

---

## 6. Potentiometer / Angle Feedback

### Reported angle is wrong or jumping around

**Check `zero_adc` and `adc_per_360` calibration.** These two config values map the raw 12-bit ADC reading to degrees:

- `zero_adc`: the raw ADC value when the shaft is at your defined 0° position
- `adc_per_360`: how many ADC counts correspond to a full 360° rotation

If these are wrong, the angle will be offset or scaled incorrectly. Use the calibration script:

```bash
# On the Pico running MicroPython
import microdrive
# Follow the manual_angle_calibrate.py procedure
```

**Noisy readings** (angle jumping ±2-3° at rest) usually mean:
- Worn potentiometer with a dead spot
- Poor connection at the pot wiper (intermittent contact on the SDA pad)
- Missing decoupling cap near the ADC input

The firmware applies a low-pass EMA filter (`alpha = 0.10`) on the ADC signal, which helps with normal noise. If readings are still jumpy, the pot may need replacement.

---

### Angle reads 0 or max constantly regardless of shaft position

The pot wiper is probably disconnected. Measure continuity from the potentiometer center pin to the **SDA** test pad. Also check that the pot end-pins are connected to **3.3V** and **GND** — if one is floating, the voltage divider doesn't work.

---

## 7. Flash / Configuration

### Config changes don't persist after power cycle

When sending a CONFIG packet, **bit 6** of the `update_mask` controls persistence:
- Bit 6 **clear** (default) → config is written to flash page 15 (`0x08003C00`)
- Bit 6 **set** → config is RAM-only (volatile, lost on reboot)

If you're using the MicroPython driver:

```python
servo.configure(kp=50.0)              # persisted to flash (default)
servo.configure(kp=50.0, volatile=True)  # RAM only, lost on reboot
```

If config *still* doesn't persist, the flash page may be corrupted. Re-flashing the firmware erases everything and resets to defaults.

---

### Want to factory-reset all config values

Re-flash the firmware. The `flash_load_config()` function checks for a `0xDEADBEEF` magic word at `0x08003C00`. If it's missing (erased flash = all `0xFF`), it writes factory defaults:

| Parameter | Default |
|---|---|
| servo_id | 0 |
| direction_invert | 0 (normal) |
| min_angle | 0° |
| max_angle | 180° |
| max_velocity | 180 deg/s |
| current_limit | 1000 mA |
| kp | 100.0 |
| ki | 0.05 |
| kd | 8.0 |
| zero_adc | 0 |
| adc_per_360 | 6600 |

---

## 8. Multi-Servo Bus

### Multiple servos on the same bus cause garbled replies

If two servos have the **same ID**, both will try to reply simultaneously, corrupting each other's packets. Every servo on the bus must have a unique ID (0–127).

To fix, disconnect all servos except one, assign it a unique ID, reconnect, and repeat:

```python
servo = bus.servo(0)  # connect to one servo at a time
servo.configure(servo_id=1)  # assign new ID
# power cycle the servo, now address it as ID 1
```

### CONTROL packets don't generate replies (by design)

This is intentional. The `0x01 CONTROL` instruction does **not** send a status reply — this was done to maximize control loop throughput on the bus. Use `0x03 POLL` to explicitly request status after sending movement commands.

---

## Quick Reference: Test Points

Use a multimeter to check these pads on the μDrive board:

| Pad | Expected | If Wrong |
|---|---|---|
| **3.3V** | 3.3V ± 5% | LDO dead or no input power |
| **GND** | 0V reference | — |
| **SDA** | 0.1V – 3.2V (varies with shaft angle) | Pot disconnected or dead |
| **PA12 bus** | 3.3V when idle | Stuck low = short or TX driver issue |
| **+VE / -VE** | Motor supply voltage | No motor power |

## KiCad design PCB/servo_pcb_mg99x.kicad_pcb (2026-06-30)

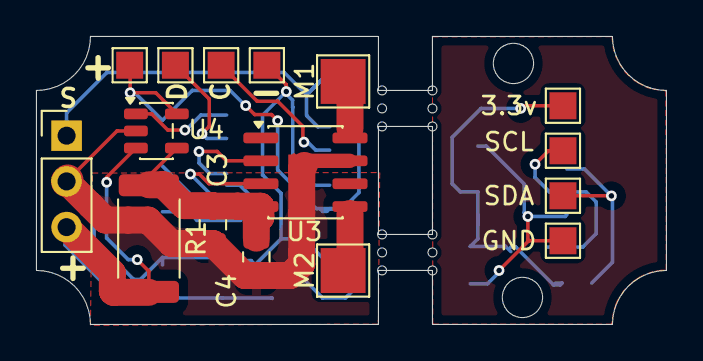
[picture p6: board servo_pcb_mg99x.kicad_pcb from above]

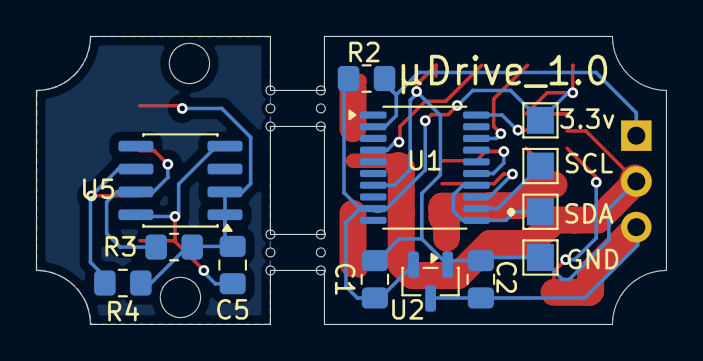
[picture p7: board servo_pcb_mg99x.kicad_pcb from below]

Board: 2 copper layers, 35.0 x 16.0 mm, 29 parts (13 on the bottom side), 18 nets.

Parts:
C1, C4: 10uf; C_0805_2012Metric_Pad1.18x1.45mm_HandSolder
C2, C3, C5: 100nf; C_0805_2012Metric_Pad1.18x1.45mm_HandSolder
J1: power in; PinHeader_1x03_P2.54mm_Vertical
M1: M1; TestPoint_Pad_2.5x2.5mm
M2: M2; TestPoint_Pad_2.5x2.5mm
R1: 0.01R; R_2512_6332Metric
R2, R3, R4: 10K; R_0805_2012Metric_Pad1.20x1.40mm_HandSolder
TP1, TP7: 3.3v; TestPoint_Pad_1.5x1.5mm
TP2, TP10: GND; TestPoint_Pad_1.5x1.5mm
TP3: SWCLK; TestPoint_Pad_1.5x1.5mm
TP4: -VE; TestPoint_Pad_1.5x1.5mm
TP5: +VE; TestPoint_Pad_1.5x1.5mm
TP6: SWIO; TestPoint_Pad_1.5x1.5mm
TP8, TP11: SDA; TestPoint_Pad_1.5x1.5mm
TP9, TP12: SCL; TestPoint_Pad_1.5x1.5mm
U1: MM32G0001; TSSOP-20_4.4x6.5mm_P0.65mm
U2: SL7533-3; SOT-23
U3: BDR6121H; SOIC-8_3.9x4.9mm_P1.27mm
U4: INA180A2; SOT-23-5
U5: AS5600; SOIC-8_3.9x4.9mm_P1.27mm

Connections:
+3.3V: C1.1, R2.1, TP5.1, TP7.1, U1.9 (VDD), U2.2 (VOUT), U4.5 (V+)
/Angle: TP8.1, U1.11 (PA4), U1.14 (PA7)
/Current Read: U1.20 (PA2), U4.1
/DATA: J1.1, R2.2, U1.2 (PA12)
/DRIVER VCC: C3.1, C4.1, R1.1, U3.4 (VDD), U4.4 (-)
/INA: U1.13 (PA6), U3.3 (INB)
/INB: U1.15 (PA8), U3.2 (INA)
/SCL: TP9.1, U1.12 (PA5)
GND: C1.2, C2.2, C3.2, C4.2, J1.2, TP4.1, TP10.1, U1.7 (VSS), U2.1 (GND), U3.7 (GND), U4.2 (GND)
unnamed: TP6.1, U1.18 (PA13/SWDIO)
unnamed: TP3.1, U1.4 (PA14/SWCLK/NRST)
unnamed: M1.1, U3.8 (OUTA)
unnamed: M2.1, U3.5 (OUTB)
unnamed: C5.2, TP2.1, U5.4 (GND), U5.8 (DIR)
unnamed: R3.2, TP12.1, U5.7 (SCL)
unnamed: R4.2, TP11.1, U5.6 (SDA)
unnamed: C5.1, R3.1, R4.1, TP1.1, U5.1 (VDD5V), U5.2 (VDD3V3)
VCC: C2.1, J1.3, R1.2, U2.3 (VIN), U4.3 (+)

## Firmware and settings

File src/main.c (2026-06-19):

#include "mm32_device.h"
#include <stdint.h>
#include <stdio.h>

#define BUF_SIZE 32
#define ANGLE_MIN 0
#define ANGLE_MAX 180
#define PID_INTERVAL_MS 1
#define INTEGRAL_LIMIT_Q8 25600000 // ~100 degree-seconds max windup limit in Q8
#define DEADBAND_Q8 256    // 1 degree deadband in Q8

// Default to 48MHz, since SystemInit configures it to 48MHz.
uint32_t SystemCoreClock = 48000000U;



// Logging Configuration (Set to 0 for silent multi-servo production daisy-chaining)
#define DEBUG_LOG 0

// Protocol packet parsing states
typedef enum {
    RX_STATE_HEADER1 = 0,
    RX_STATE_HEADER2,
    RX_STATE_ID,
    RX_STATE_LENGTH,
    RX_STATE_INSTRUCTION,
    RX_STATE_PARAMETERS,
    RX_STATE_CHECKSUM
} RxState;

// Configuration structure matching implementation specification (26 bytes)
typedef struct __attribute__((packed)) {
    uint8_t  servo_id;        // 0-127, default: 0
    uint8_t  direction_invert;// 0 = normal, 1 = inverted motor direction
    uint16_t min_angle;       // minimum angle, e.g., 45
    uint16_t max_angle;       // maximum angle, e.g., 280
    uint16_t max_velocity;    // degrees per second, default e.g. 180
    uint16_t current_limit;   // raw current ADC threshold (or mA threshold), default e.g. 1000
    int32_t  kp_q16;          // PID proportional gain
    int32_t  ki_q16;          // PID integral gain
    int32_t  kd_q16;          // PID derivative gain
    int16_t  zero_adc;        // raw ADC value at exactly 0 degrees
    int16_t  adc_per_360;     // number of ADC ticks for 360 degree rotation (signed)
    uint32_t magic;           // 0xDEADBEEF Magic Word
} ServoConfig;

// Global variables
ServoConfig config;

// PID active fixed-point gains (pre-calculated for 1ms time-step)
volatile int32_t Kp_q16;
volatile int32_t Ki_q16;
volatile int32_t Ki_scaled_q16;
volatile int32_t Kd_q16;
volatile int32_t adc_to_angle_mult_q16;

// PID state variables (pure integer, Q8 fixed-point format)
int32_t pid_error = 0;
int32_t pid_integral = 0;
int32_t prev_error = 0;

volatile uint8_t pending_reply_cmd = 0;
volatile uint32_t reply_trigger_time_ms = 0;
int32_t pid_derivative = 0;

// Motion target, trajectory profiling (Ghost Target) and feedback
volatile int32_t target_angle = 150;      // default target (degrees)
volatile int32_t ghost_angle_q8 = 150*256; // Ghost Target in Q8
volatile int32_t current_angle = 0;       // Current physical angle
volatile int32_t current_angle_q8 = 0;    // Current physical angle in Q8
volatile uint16_t active_velocity = 180;  // Active velocity in deg/s
volatile uint16_t active_current_limit = 1000; // Active admittance force limit (mA)
volatile uint8_t yield_active = 0;        // Flag for admittance yielding
volatile int32_t pwm_clamp = 2399;        // Dynamic PWM clamp for holding force
volatile uint8_t status_reporting_enabled = 0;

#define HARD_OCP_LIMIT_MA 2000            // Absolute safety hard-fault limit

// Safety and Fault Management flags
volatile uint8_t overcurrent_fault = 0;
volatile uint32_t overcurrent_ms = 0;
volatile uint8_t motor_armed = 0; // Arm on first valid CONTROL packet
volatile int32_t zero_current_offset_adc = 0; // Startup auto-zero calibration offset



void print_status(void);
void send_config_reply(void);

// Flash Erase/Write Helper Functions
void flash_erase_page(uint32_t address) {
    if (READ_BIT(FLASH->CR, FLASH_CR_LOCK)) {
        WRITE_REG(FLASH->KEYR, 0x45670123);
        WRITE_REG(FLASH->KEYR, 0xCDEF89AB);
    }
    WRITE_REG(FLASH->SR, FLASH_SR_EOP | FLASH_SR_WRPRTERR | FLASH_SR_PGERR);
    SET_BIT(FLASH->CR, FLASH_CR_PER);
    WRITE_REG(FLASH->AR, address);
    SET_BIT(FLASH->CR, FLASH_CR_STRT);
    while (READ_BIT(FLASH->SR, FLASH_SR_BSY));
    CLEAR_BIT(FLASH->CR, FLASH_CR_PER);
    WRITE_REG(FLASH->SR, FLASH_SR_EOP | FLASH_SR_WRPRTERR | FLASH_SR_PGERR);
}

void flash_write_halfword(uint32_t address, uint16_t data) {
    SET_BIT(FLASH->CR, FLASH_CR_PG);
    *(volatile uint16_t *)address = data;
    while (READ_BIT(FLASH->SR, FLASH_SR_BSY));
    CLEAR_BIT(FLASH->CR, FLASH_CR_PG);
    WRITE_REG(FLASH->SR, FLASH_SR_EOP | FLASH_SR_WRPRTERR | FLASH_SR_PGERR);
}

void flash_write_config(ServoConfig *cfg) {
    // 1. Temporarily force motor compare registers to 0 for safety
    TIM_SetCompare3(TIM1, 0);
    TIM_SetCompare2(TIM1, 0);

    // 2. Erase flash page 15 (last 1KB of 16KB FLASH, starting at 0x08003C00)
    flash_erase_page(0x08003C00);

    // 3. Write config struct (rounded up to write final odd byte safely if struct size changes, pure compile-time integer math)
    uint16_t *src = (uint16_t *)cfg;
    for (size_t i = 0; i < (sizeof(ServoConfig) + 1) / 2; i++) {
        flash_write_halfword(0x08003C00 + i * 2, src[i]);
    }

    // 4. Re-lock Flash Memory
    SET_BIT(FLASH->CR, FLASH_CR_LOCK);
}

void flash_load_config(ServoConfig *cfg) {
    ServoConfig *flash_cfg = (ServoConfig *)0x08003C00;
    if (flash_cfg->magic == 0xDEADBEEF) {
        *cfg = *flash_cfg;
    } else {
        // Load default parameters
        cfg->servo_id = 0; // Default ID is 0 as explicitly requested!
        cfg->direction_invert = 0; // Default direction: normal (0)
        cfg->min_angle = ANGLE_MIN;
        cfg->max_angle = ANGLE_MAX;
        cfg->max_velocity = 180; // default 180 degrees/sec
        cfg->current_limit = 1000; // raw threshold/mA limit
        cfg->kp_q16 = 6553600;     // Kp = 100.0 * 65536
        cfg->ki_q16 = 3276;        // Ki = 0.05 * 65536 (unscaled)
        cfg->kd_q16 = 524288;      // Kd = 8.0 * 65536 (unscaled)
        cfg->zero_adc = 0;         // Default 0
        cfg->adc_per_360 = 6600;   // Default 6600
        cfg->magic = 0xDEADBEEF;

        // Persist default config to flash
        flash_write_config(cfg);
    }
    
    if (cfg->adc_per_360 == 0) cfg->adc_per_360 = 1;
    adc_to_angle_mult_q16 = (360 << 16) / cfg->adc_per_360;

    // Keep unscaled Q16 gains for high-precision dynamic scaling in PID loop
    Kp_q16 = cfg->kp_q16;
    Ki_q16 = cfg->ki_q16;
    Ki_scaled_q16 = (cfg->ki_q16 * 16777) >> 24;
    Kd_q16 = cfg->kd_q16;
}

// System Init
void SystemInit(void) {
    RCC->CR |= RCC_CR_HSION;
    while (!(RCC->CR & RCC_CR_HSIRDY));
    
    FLASH->ACR &= ~FLASH_ACR_LATENCY_Msk;
    FLASH->ACR |= FLASH_ACR_LATENCY_1;
    FLASH->ACR |= FLASH_ACR_PRFTBE;
    
    RCC->CFGR &= ~RCC_CFGR_HPRE_Msk;
    RCC->CFGR |= (0x00U << RCC_CFGR_HPRE_Pos);
    
    RCC->CFGR &= ~RCC_CFGR_PPRE1_Msk;
    RCC->CFGR |= (0x00U << RCC_CFGR_PPRE1_Pos);
    
    RCC->CFGR &= ~RCC_CFGR_SW_Msk;
    RCC->CFGR |= (0x02U << RCC_CFGR_SW_Pos);
    
    while ((RCC->CFGR & RCC_CFGR_SWS_Msk) != (0x02U << RCC_CFGR_SWS_Pos)) {
        __ASM("nop");
    }
    
    SystemCoreClock = 48000000U;
}

void delay_ms(uint32_t ms) {
    for (volatile uint32_t i = 0; i < ms * 6000; i++) {
        __ASM("nop");
    }
}

// UART Half-Duplex Single-Wire Helper Functions
void uart_enable_tx(void) {
    USART_ITConfig(USART1, USART_IT_RXNE, DISABLE);
    USART_RxCmd(USART1, DISABLE);
    USART_TxCmd(USART1, ENABLE);
}

void uart_enable_rx(void) {
    while (USART_GetFlagStatus(USART1, USART_FLAG_TC) == RESET);
    USART_TxCmd(USART1, DISABLE);
    USART_RxCmd(USART1, ENABLE);
    USART_ITConfig(USART1, USART_IT_RXNE, ENABLE);
}

void uart_init(void) {
    GPIO_InitTypeDef GPIO_InitStruct;
    USART_InitTypeDef USART_InitStruct;

    RCC_AHBPeriphClockCmd(RCC_AHBPERIPH_GPIOA, ENABLE);
    RCC_APB1PeriphClockCmd(RCC_APB1PERIPH_USART1, ENABLE);

    GPIO_StructInit(&GPIO_InitStruct);
    GPIO_InitStruct.GPIO_Pin   = GPIO_Pin_12;
    GPIO_InitStruct.GPIO_Speed = GPIO_Speed_High;
    GPIO_InitStruct.GPIO_Mode  = GPIO_Mode_AF_OD; // Open-Drain for single-wire Shared Bus
    GPIO_Init(GPIOA, &GPIO_InitStruct);

    GPIO_PinAFConfig(GPIOA, GPIO_PinSource12, GPIO_AF_1);

    USART_StructInit(&USART_InitStruct);
    USART_InitStruct.USART_BaudRate   = 250000;
    USART_InitStruct.USART_WordLength = USART_WordLength_8b;
    USART_InitStruct.USART_StopBits   = USART_StopBits_1;
    USART_InitStruct.USART_Parity     = USART_Parity_No;
    USART_InitStruct.USART_Mode       = USART_Mode_Rx; // Start listening initially
    USART_Init(USART1, &USART_InitStruct);

    // Enable USART1 RX Interrupt
    USART_ITConfig(USART1, USART_IT_RXNE, ENABLE);
    
    // Configure NVIC for USART1
    NVIC_InitTypeDef NVIC_InitStruct;
    NVIC_InitStruct.NVIC_IRQChannel = USART1_IRQn;
    NVIC_InitStruct.NVIC_IRQChannelPriority = 0; // Set to highest priority to prevent overrun during SysTick ADC loop
    NVIC_InitStruct.NVIC_IRQChannelCmd = ENABLE;
    NVIC_Init(&NVIC_InitStruct);

    USART_HalfDuplexCmd(USART1, ENABLE);
    USART_Cmd(USART1, ENABLE);
}

void uart_putchar_raw(char c) {
    while (USART_GetFlagStatus(USART1, USART_FLAG_TXE) == RESET);
    USART_SendData(USART1, (uint16_t)c);
}

void uart_print(const char *str) {
    uart_enable_tx();
    while (*str) {
        if (*str == '\n') {
            uart_putchar_raw('\r');
        }
        uart_putchar_raw(*str++);
    }
    uart_enable_rx();
}

void uart_print_int(uint32_t val) {
    char buf[12];
    int i = 10;
    buf[11] = '\0';
    if (val == 0) {
        uart_print("0");
        return;
    }
    while (val > 0 && i >= 0) {
        buf[i--] = (val % 10) + '0';
        val /= 10;
    }
    uart_print(&buf[i + 1]);
}

// 1ms SysTick interrupts
volatile uint32_t ms_ticks = 0;
uint32_t active_timer_period = 2399;
static inline void one_ms_task(uint32_t arr_period);

void SysTick_Handler(void) {
    ms_ticks++;
    // Guarantee that the PID loop runs exactly every 1ms, 
    // even if the main loop is blocked sending UART replies!
    one_ms_task(active_timer_period);
}

uint32_t millis(void) {
    return ms_ticks;
}

// ADC Helper Functions
void adc_init(void) {
    ADC_InitTypeDef  ADC_InitStruct;
    GPIO_InitTypeDef GPIO_InitStruct;

    // 1. Enable ADC1 peripheral clock
    RCC_APB1PeriphClockCmd(RCC_APB1PERIPH_ADC1, ENABLE);

    // 2. Initialize ADC1
    ADC_StructInit(&ADC_InitStruct);
    ADC_InitStruct.ADC_Resolution       = ADC_Resolution_12b;
    ADC_InitStruct.ADC_Prescaler        = ADC_Prescaler_3; // 16MHz ADC clock @ 48MHz PCLK
    ADC_InitStruct.ADC_Mode             = ADC_Mode_Imm;
    ADC_InitStruct.ADC_DataAlign        = ADC_DataAlign_Right;
    ADC_Init(ADC1, &ADC_InitStruct);

    // 3. Configure sampling time for fast and safe settling (14.5 + 12.5 = 27 cycles @ 8MHz = 3.3us)
    ADC_SampleTimeConfig(ADC1, ADC_SampleTime_14_5);

    // 4. Configure PA7, PA4, and PA2 as Analog Inputs (AIN)
    // Note: PA4 is tied to PA7 on the PCB. We set PA4 to AIN to safely disable its digital buffer.
    RCC_AHBPeriphClockCmd(RCC_AHBPERIPH_GPIOA, ENABLE);
    GPIO_StructInit(&GPIO_InitStruct);
    GPIO_InitStruct.GPIO_Pin   = GPIO_Pin_7 | GPIO_Pin_4 | GPIO_Pin_2;
    GPIO_InitStruct.GPIO_Speed = GPIO_Speed_High;
    GPIO_InitStruct.GPIO_Mode  = GPIO_Mode_AIN;
    GPIO_Init(GPIOA, &GPIO_InitStruct);

    // 5. Enable ADC1
    ADC_Cmd(ADC1, ENABLE);
}

static inline uint16_t adc_read(uint8_t channel) {
    static uint8_t last_channel = 0xFF;
    
    uint32_t primask = __get_PRIMASK();
    __disable_irq();
    
    ADC_AnyChannelNumCfg(ADC1, 0);
    ADC_AnyChannelSelect(ADC1, ADC_AnyChannel_0, channel);
    ADC_AnyChannelCmd(ADC1, ENABLE);

    // 1. Perform dummy conversion ONLY if we switched channels to let the S&H capacitor settle
    if (channel != last_channel) {
        last_channel = channel;
        
        ADC_SoftwareStartConvCmd(ADC1, ENABLE);
        while (RESET == ADC_GetFlagStatus(ADC1, ADC_FLAG_EOC)) {
            __ASM("nop");
        }
        ADC_ClearFlag(ADC1, ADC_FLAG_EOC);
        (void)ADC_GetConversionValue(ADC1);
    }

    // 2. Perform actual high-precision conversion
    ADC_SoftwareStartConvCmd(ADC1, ENABLE);
    while (RESET == ADC_GetFlagStatus(ADC1, ADC_FLAG_EOC)) {
        __ASM("nop");
    }

    ADC_ClearFlag(ADC1, ADC_FLAG_EOC);
    uint16_t value = ADC_GetConversionValue(ADC1);

    ADC_AnyChannelCmd(ADC1, DISABLE);

    __set_PRIMASK(primask);
    return value;
}

static void motor_set_pwm_pair(uint32_t arr_period, uint32_t ccr3, uint32_t ccr2) {
    TIM_SetCompare3(TIM1, ccr3);
    TIM_SetCompare2(TIM1, ccr2);
}

volatile int32_t latest_current_ma = 0;

static inline int32_t update_current_ma(void) {
    static int32_t filtered_current_q8 = -1;

    // Perform a single synchronous ADC read (incorporates settling dummy read internally if channel changed)
    uint16_t raw_adc = adc_read(ADC_Channel_5);
    
    // Apply baseline offset calibration
    int32_t corrected_raw = (int32_t)raw_adc - zero_current_offset_adc;
    if (corrected_raw < 0) {
        corrected_raw = 0;
    }
    
    // Scale standard integer calculation directly to Q8 format
    // Multiplier (387973 >> 10) calibrated using DC resistor test (Slope = 1.480 mA/count)
    // Use unsigned 32-bit multiply to avoid signed overflow, then cast back.
    int32_t current_ma_q8 = (int32_t)(((uint32_t)corrected_raw * 387973U) >> 10);
    
    if (filtered_current_q8 < 0) {
        filtered_current_q8 = current_ma_q8;
    } else {
        // Apply EMA filter: alpha = 0.15 -> Q8 weight is 38/256
        filtered_current_q8 = (38 * current_ma_q8 + 218 * filtered_current_q8) >> 8;
    }
    
    latest_current_ma = (filtered_current_q8 >> 8);
    return latest_current_ma; // convert back to standard integer milliamps
}

static inline int32_t get_current_ma(void) {
    return latest_current_ma;
}

// Transmit immediate status packet reply (echoing instruction)
void send_status_reply(uint8_t echoed_instruction) {
    
    uint8_t packet[11];
    packet[0] = 0xFF;
    packet[1] = 0xFF;
    packet[2] = config.servo_id;
    packet[3] = 0x07; // Length: Instruction (1) + 5 Params + Checksum (1)
    packet[4] = echoed_instruction;
    
    // Param 0,1: Current Angle (LSB/MSB)
    packet[5] = (uint8_t)(current_angle & 0xFF);
    packet[6] = (uint8_t)((current_angle >> 8) & 0xFF);
    
    // Param 2,3: Current Draw (LSB/MSB)
    int32_t current_ma = get_current_ma();
    packet[7] = (uint8_t)(current_ma & 0xFF);
    packet[8] = (uint8_t)((current_ma >> 8) & 0xFF);
    
    // Param 4: Status Flags (Bit 0: Moving, Bit 1: Over_Current, Bit 2: Holding)
    uint8_t flags = 0;
    if (status_reporting_enabled) {
        flags |= (1 << 0);
    }
    if (overcurrent_fault) {
        flags |= 0x02;
    }
    if (yield_active) {
        flags |= 0x04;
    }
    packet[9] = flags;
    
    // Checksum: lower 8 bits of bitwise NOT of sum of ID to last parameter
    uint8_t sum = packet[2] + packet[3] + packet[4] + packet[5] + packet[6] + packet[7] + packet[8] + packet[9];
    packet[10] = ~sum;
    
    // Transmit over shared single-wire bus
    uart_enable_tx();
    for (int i = 0; i < 11; i++) {
        uart_putchar_raw((char)packet[i]);
    }
    uart_enable_rx();
}

void send_config_reply(void) {
    
    uint8_t packet[36];
    packet[0] = 0xFF;
    packet[1] = 0xFF;
    packet[2] = config.servo_id;
    packet[3] = 32; // Length: Instruction (1) + 30 Params + Checksum (1)
    packet[4] = 0x05; // Echoed Instruction
    
    // Copy the entire 30-byte config struct as parameters
    uint8_t *config_bytes = (uint8_t *)&config;
    for (int i = 0; i < 30; i++) {
        packet[5 + i] = config_bytes[i];
    }
    
    // Checksum: lower 8 bits of bitwise NOT of sum of ID to last parameter
    uint8_t sum = packet[2] + packet[3] + packet[4];
    for (int i = 0; i < 30; i++) {
        sum += packet[5 + i];
    }
    packet[35] = ~sum;
    
    // Transmit over shared single-wire bus
    uart_enable_tx();
    for (int i = 0; i < 36; i++) {
        uart_putchar_raw((char)packet[i]);
    }
    uart_enable_rx();
}
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
int main(void) {
    // Synchronize the SystemCoreClock variable with the actual hardware PLL speed
    // The C-runtime initialization overwrites the value set in SystemInit(), so we restore it here.
    SystemCoreClock = 48000000U;

    GPIO_InitTypeDef        GPIO_InitStruct;
    TIM_TimeBaseInitTypeDef TIM_TimeBaseStruct;
    TIM_OCInitTypeDef       TIM_OCInitStruct;

    // (SysTick will be enabled at the end of initialization to prevent interrupt race conditions)

    // 2. Initialize Single-Wire Half-Duplex USART1 at 250000 Baud
    uart_init();
#if DEBUG_LOG
    uart_print("\n--- Microdrive Firmware Init ---\n");
#endif

    // 3. Load or initialize Flash Persistent Parameters
    flash_load_config(&config);
#if DEBUG_LOG
    uart_print("Flash Loaded Configuration ID: ");
    uart_print_int(config.servo_id);
    uart_print("\r\n");
#endif

    // 4. Initialize TIM1 and GPIOA
    RCC_APB1PeriphClockCmd(RCC_APB1PERIPH_TIM1, ENABLE);
    RCC_AHBPeriphClockCmd(RCC_AHBPERIPH_GPIOA, ENABLE);

    // 5. Configure TIM1 base for 20kHz motor PWM
    uint32_t TimerClock = TIM_GetTIMxClock(TIM1);
    uint32_t TargetFrequency = 20000;
    uint32_t TimerPeriod = (TimerClock / TargetFrequency) - 1;
    active_timer_period = TimerPeriod;

    TIM_TimeBaseStructInit(&TIM_TimeBaseStruct);
    TIM_TimeBaseStruct.TIM_Prescaler         = 0;
    TIM_TimeBaseStruct.TIM_CounterMode       = TIM_CounterMode_Up;
    TIM_TimeBaseStruct.TIM_Period            = TimerPeriod;
    TIM_TimeBaseStruct.TIM_ClockDivision     = TIM_CKD_Div1;
    TIM_TimeBaseStruct.TIM_RepetitionCounter = 0;
    TIM_TimeBaseInit(TIM1, &TIM_TimeBaseStruct);

    // 6. Initialize TIM1 CH3 and CH2 output channels
    TIM_OCStructInit(&TIM_OCInitStruct);
    TIM_OCInitStruct.TIM_OCMode       = TIM_OCMode_Timing;
    TIM_OCInitStruct.TIM_OutputState  = TIM_OutputState_Enable;
    TIM_OCInitStruct.TIM_Pulse        = 0;
    TIM_OCInitStruct.TIM_OCPolarity   = TIM_OCPolarity_High;
    TIM_OCInitStruct.TIM_OCIdleState  = TIM_OCIdleState_Reset;
    TIM_OC3Init(TIM1, &TIM_OCInitStruct); // Channel 3 (PA6)
    TIM_OC2Init(TIM1, &TIM_OCInitStruct); // Channel 2 (PA8)

    TIM_OCInitStruct.TIM_OCMode       = TIM_OCMode_PWM1;
    TIM_OCInitStruct.TIM_OutputState  = TIM_OutputState_Enable;
    TIM_OCInitStruct.TIM_OCIdleState  = TIM_OCIdleState_Set;
    TIM_OC3Init(TIM1, &TIM_OCInitStruct); // Channel 3 (PA6)
    TIM_OC2Init(TIM1, &TIM_OCInitStruct); // Channel 2 (PA8)

    // 7. Configure pin AF multiplexing
    GPIO_PinAFConfig(GPIOA, GPIO_PinSource6, GPIO_AF_4);
    GPIO_PinAFConfig(GPIOA, GPIO_PinSource8, GPIO_AF_1);

    // 8. Configure Alternate Function push-pull pins for PWM channels
    GPIO_StructInit(&GPIO_InitStruct);
    GPIO_InitStruct.GPIO_Pin   = GPIO_Pin_6 | GPIO_Pin_8;
    GPIO_InitStruct.GPIO_Speed = GPIO_Speed_High;
    GPIO_InitStruct.GPIO_Mode  = GPIO_Mode_AF_PP;
    GPIO_Init(GPIOA, &GPIO_InitStruct);

    // 9. Configure Software Reset button on PA0
    GPIO_StructInit(&GPIO_InitStruct);
    GPIO_InitStruct.GPIO_Pin   = GPIO_Pin_0;
    GPIO_InitStruct.GPIO_Speed = GPIO_Speed_High;
    GPIO_InitStruct.GPIO_Mode  = GPIO_Mode_IPU; // Input Pull-Up
    GPIO_Init(GPIOA, &GPIO_InitStruct);

    // 10. Initialize ADC on PA7 and PA2
    adc_init();

    // Calibrate current sensor baseline offset (Auto-Zeroing)
    calibrate_current_sensor();

    // 11. Enable TIM1 Main Outputs
    TIM_Cmd(TIM1, ENABLE);
    TIM_CtrlPWMOutputs(TIM1, ENABLE);

    // 12. Soft Start: read current position to lock initial target securely
    uint16_t init_raw_adc = adc_read(ADC_Channel_7);
    int32_t init_active_adc_q8 = ((int32_t)init_raw_adc - config.zero_adc) << 8;
    int32_t init_angle_q8 = (int32_t)(((int64_t)init_active_adc_q8 * adc_to_angle_mult_q16) >> 16);
    
    current_angle_q8 = init_angle_q8;
    current_angle = (init_angle_q8 + 128) >> 8;
    target_angle = current_angle;
    ghost_angle_q8 = init_angle_q8;
    active_velocity = config.max_velocity;
    motor_set_pwm_pair(active_timer_period, 0, 0);

#if DEBUG_LOG
    uart_print("Soft-Start Complete. Locked Initial Angle: ");
    uart_print_int(current_angle);
    uart_print(" deg.\r\n");
#endif

    // 13. Enable 1ms SysTick timekeeping interrupt and PID Loop
    SysTick_Config(SystemCoreClock / 1000);
    NVIC_SetPriority(SysTick_IRQn, 1); // Set to priority 1 (lower than USART1) to allow preemptive serial reading

    // 14. Enable Independent Watchdog (IWDG) — ~500ms timeout, auto-resets MCU if main loop hangs
    // IWDG->KR  = 0x5555;   // Unlock prescaler and reload registers
    // IWDG->PR  = 4;         // Prescaler /64: 40kHz LSI / 64 = 625 Hz
    // IWDG->RLR = 312;       // Reload value: 312 / 625 Hz ≈ 500ms timeout
    // while (IWDG->SR);      // Wait for registers to sync
    // IWDG->KR  = 0xAAAA;   // Initial reload
    // IWDG->KR  = 0xCCCC;   // Start IWDG (cannot be stopped once started)

    while (1) {
        // Pet the watchdog — if we ever fail to reach this line within 500ms, MCU hard-resets
        // IWDG->KR = 0xAAAA;
        // A. Software System Reset Trigger (Debounced reset button on PA0)
        if (GPIO_ReadInputDataBit(GPIOA, GPIO_Pin_0) == Bit_RESET) {
#if DEBUG_LOG
            uart_print("\r\n[RESET] Triggering Software Reset via PA0...\r\n");
#endif
            delay_ms(50);
            NVIC_SystemReset();
        }
        
        // C. Send asynchronous TX replies safely without blocking the CPU
        if (pending_reply_cmd != 0 && millis() >= reply_trigger_time_ms) {
            if (pending_reply_cmd == 0x05) {
                send_config_reply();
            } else {
                send_status_reply(pending_reply_cmd);
            }
            pending_reply_cmd = 0;
        }

        // D. (PID loop is now handled purely in the background by SysTick_Handler!)
    }
}

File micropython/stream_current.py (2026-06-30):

"""
Live current streaming utility for Microdrive.
Reads and prints the current draw of a selected servo at regular intervals.
"""

from machine import UART, Pin
import time
import sys
from microdrive import ServoBus

def stream_live_current():
    uart = UART(1, baudrate=250000, tx=Pin(4), rx=Pin(5))
    bus = ServoBus(uart)

    print("Scanning for active servos...")
    found = bus.scan(id_range=range(0, 6))
    if not found:
        print("No servos detected.")
        return

    target_id = found[0][0]
    print(f"Targeting servo ID {target_id}")
    servo = bus.servo(target_id)
    
    print("\nLive Current draw (mA):")
    print("Press Ctrl+C to stop.\n")
    
    try:
        while True:
            status = servo.poll()
            if status:
                print(f"\rCurrent: {status.current_ma:4d} mA   ", end="")
            else:
                print("\rFailed to read servo.         ", end="")
            time.sleep_ms(50)
            
    except KeyboardInterrupt:
        print("\nStopped.")

if __name__ == "__main__":
    stream_live_current()

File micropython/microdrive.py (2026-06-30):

"""
microdrive.py — MicroPython driver for Microdrive (MM32 firmware)

Communicates over a half-duplex single-wire UART bus at 250000 baud.
Protocol: binary packets with 0xFF 0xFF header, ID, length, instruction,
parameters (little-endian), and inverted-sum checksum.

Supports daisy-chained servos on the same bus, each addressed by a unique ID.

Usage:
    from machine import UART, Pin
    from microdrive import ServoBus

    bus = ServoBus(UART(1, 250000), dir_pin=Pin(4, Pin.OUT))
    servo = bus.servo(0)
    servo.move(180, velocity=200)
    status = servo.poll()
    print(status)
"""

import struct
import time

# Protocol Constants

_HEADER          = b'\xff\xff'
_BROADCAST_ID    = 0xFE

_INST_CONTROL    = 0x01
_INST_CONFIG     = 0x02
_INST_POLL       = 0x03
_INST_CLEAR_ERR  = 0x04
_INST_READ_CONFIG = 0x05

_STATUS_REPLY_LEN = 11  # Total bytes in a status reply packet
_CONFIG_REPLY_LEN = 36  # Total bytes in a configuration reply packet

# CONFIG update mask bits
_MASK_ID_DIR     = 1 << 0
_MASK_ANGLE_LIM  = 1 << 1
_MASK_VELOCITY   = 1 << 2
_MASK_CURRENT    = 1 << 3
_MASK_PID        = 1 << 4
_MASK_HARD_CAL   = 1 << 5
_MASK_RAM_ONLY   = 1 << 6

# Reply timeout (ms) — optimized for fast RP2040 turnaround (active node replies in ~2.7ms)
_REPLY_TIMEOUT_MS = 8


# Status Reply Container

class ServoStatus:
    """Parsed status reply from the servo."""

    __slots__ = ('servo_id', 'instruction', 'angle', 'current_ma',
                 'is_moving', 'overcurrent', 'is_holding')

    def __init__(self, servo_id, instruction, angle, current_ma, flags):
        self.servo_id    = servo_id
        self.instruction = instruction
        self.angle       = angle
        self.current_ma  = current_ma
        self.is_moving   = bool(flags & 0x01)
        self.overcurrent = bool(flags & 0x02)
        self.is_holding  = bool(flags & 0x04)

    @property
    def has_fault(self):
        """True if any fault flag is active."""
        return self.overcurrent

    def __repr__(self):
        parts = [
            'angle={}°'.format(self.angle),
            'current={}mA'.format(self.current_ma),
        ]
        flags = []
        if self.is_moving:
            flags.append('MOVING')
        if self.is_holding:
            flags.append('HOLDING')
        if self.overcurrent:
            flags.append('OVERCURRENT')
        if flags:
            parts.append('flags=' + '|'.join(flags))
        return '<ServoStatus {}>'.format(' '.join(parts))


# Configuration Reply Container
class ServoConfigData:
    """Parsed configuration stored in the servo's flash memory."""

    __slots__ = ('servo_id', 'direction_invert', 'min_angle', 'max_angle',
                 'max_velocity', 'current_limit', 'kp', 'ki', 'kd',
                 'zero_adc', 'adc_per_360', 'magic')

    def __init__(self, servo_id, direction_invert, min_angle, max_angle,
                 max_velocity, current_limit, kp_q16, ki_q16, kd_q16,
                 zero_adc, adc_per_360, magic):
        self.servo_id         = servo_id
        self.direction_invert = bool(direction_invert)
        self.min_angle        = min_angle
        self.max_angle        = max_angle
        self.max_velocity     = max_velocity
        self.current_limit    = current_limit
        self.kp               = _q16_to_float(kp_q16)
        self.ki               = _q16_to_float(ki_q16)
        self.kd               = _q16_to_float(kd_q16)
        self.zero_adc         = zero_adc
        self.adc_per_360      = adc_per_360
        self.magic            = magic

    def __repr__(self):
        return (
            "<ServoConfigData id={} dir_invert={} limits={}°-{}° "
            "max_vel={} current_lim={}mA kp={:.2f} ki={:.4f} kd={:.2f} zero_adc={} adc_per_360={} magic={:#X}>"
        ).format(
            self.servo_id, self.direction_invert, self.min_angle, self.max_angle,
            self.max_velocity, self.current_limit, self.kp, self.ki, self.kd,
            self.zero_adc, self.adc_per_360, self.magic
        )


def _parse_config_reply(raw):
    """
    Parse a 36-byte configuration reply packet.
    Returns a ServoConfigData or None if the packet is invalid.
    """
    if len(raw) != _CONFIG_REPLY_LEN:
        return None
    if raw[0] != 0xFF or raw[1] != 0xFF:
        return None

    sid   = raw[2]
    length = raw[3]
    inst  = raw[4]

    if length != 32:  # instruction (1) + params (30) + checksum (1)
        return None

    # Verify checksum (bytes 2..34 -> checksum at byte 35)
    expected = _checksum(raw[2:35])
    if raw[35] != expected:
        return None

    # Unpack the 30 parameter bytes
    params = raw[5:35]
    unpacked = struct.unpack('<BBHHHHiiihhI', params)
    
    return ServoConfigData(*unpacked)


# Low-level Packet Helpers

def _checksum(data):
    """Compute protocol checksum: ~(sum of bytes) & 0xFF."""
    return (~sum(data)) & 0xFF


def _build_packet(servo_id, instruction, params=b''):
    """Assemble a complete protocol packet as bytes."""
    length = 1 + len(params) + 1  # instruction + params + checksum
    body = bytes([servo_id, length, instruction]) + params
    chk = _checksum(body)
    return _HEADER + body + bytes([chk])


def _parse_status_reply(raw):
    """
    Parse an 11-byte status reply packet.
    Returns a ServoStatus or None if the packet is invalid.
    """
    if len(raw) != _STATUS_REPLY_LEN:
        return None
    if raw[0] != 0xFF or raw[1] != 0xFF:
        return None

    sid   = raw[2]
    length = raw[3]
    inst  = raw[4]

    if length != 0x07:
        return None

    # Verify checksum (bytes 2..9 -> checksum at byte 10)
    expected = _checksum(raw[2:10])
    if raw[10] != expected:
        return None

    angle      = raw[5] | (raw[6] << 8)
    if angle >= 32768:
        angle -= 65536
        
    current_ma = raw[7] | (raw[8] << 8)
    flags      = raw[9]

    return ServoStatus(sid, inst, angle, current_ma, flags)


# Fixed-point conversion helpers

def _float_to_q16(value):
    """Convert a float PID gain to Q16 fixed-point (signed int32)."""
    raw = int(value * 65536)
    # Clamp to signed 32-bit range
    if raw > 0x7FFFFFFF:
        raw = 0x7FFFFFFF
    elif raw < -0x80000000:
        raw = -0x80000000
    return raw


def _q16_to_float(raw):
    """Convert a Q16 fixed-point int32 back to float."""
    # Handle signed 32-bit
    if raw >= 0x80000000:
        raw -= 0x100000000
    return raw / 65536.0


def _pack_u16_le(val):
    """Pack an unsigned 16-bit integer as 2 little-endian bytes."""
    return struct.pack('<H', val)


# Servo Bus Manager
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

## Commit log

2026-06-07 Initial commmit for MicroDrive
    [servo_pcb.kicad_pcb, servo_pcb.kicad_sch, servo_pcb_multi.kicad_sch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]
2026-06-07 Cleaned up PCB folder and updated readme, updated pcb
    [servo_pcb.kicad_sch, servo_pcb_mg99x.kicad_pcb, servo_pcb_multi.kicad_sch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]
2026-06-08 cleaned up older pcbs and updated the master pcb
    [servo_pcb.kicad_pcb, servo_pcb_v1.0.0.kicad_pcb, servo_pcb_v1.0.5.kicad_pcb]
2026-06-08 updated pcb:added ground pours
    [servo_pcb.kicad_pcb, servo_pcb_mg99x.kicad_pcb]
2026-06-10 updated the pcb for generic motors
    [servo_pcb-mg99x.kicad_sch, servo_pcb.kicad_pcb, servo_pcb_mg99x.kicad_pcb]
2026-06-11 updated docs
    [servo_pcb-mg99x.kicad_sch, servo_pcb.kicad_sch]
2026-06-12 fix: add hardware watchdog (IWDG) and disable debug UART from ISR context
    - Enable IWDG with ~500ms timeout for automatic MCU recovery when
    main loop hangs (no manual reset or power cycle needed)
    - Set DEBUG_LOG=0 to eliminate SysTick/UART race condition where
    print_status() from pid_update() could preempt send_status_reply()
    mid-transmission, permanently deadlocking the UART in RX mode
    - Add PA11 reset button footprint to PCB
    - Rewrite docs/troubleshoot.md with practical symptom-to-fix format
    [servo_pcb.kicad_pcb]
2026-06-13 docs: added OSHWA certification, contributing guide, and issue templates
    [servo_pcb.kicad_pcb, servo_pcb.kicad_sch, servo_pcb_mg99x.kicad_sch]
2026-06-19 feat: refactor current sampling to interrupts and build a GUI calibration wizard & step tester
    Firmware:
    - Replaced CPU-blocking polling loop in current sampling with an interrupt-driven mechanism to capture motor phase current at the PWM midpoint.
    - Added IRQ disabling/restoring in `adc_read()` to prevent race conditions and state corruption during concurrent ADC reads.
    - Extracted direct timer PWM compare writes into a helper `motor_set_pwm_pair` for cleaner register management.
    - Commented out IWDG watchdog configuration due to improper initialization
    - Configured SysTick NVIC priority to 0 (highest).
    GUI / Dashboard:
    - Added `CalibrationWizard.svelte` to walk users through ID setup, pot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
    [main.c]
2026-06-19 docs: align documentation and comments with implementation specifications
    - Correct Servo ID range to 0-127 (due to 7-bit packing with direction bit) in docs and main.c comment
    - Update ServoConfig struct size documentation to 30 bytes (accounting for the 4-byte magic word)
    - Document the soft current limiting (admittance yield loop) algorithm and ISR priorities in docs/firmware.md
    - Update is_holding API description to reflect admittance yield compliance mode
    - Add the missing dir_pin constructor parameter to the ServoBus class documentation
    - Fix the MG99x schematic filename in docs/hardware.md
    - Add Arduino/C++ driver development to the project roadmap in READM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
    [main.c]
2026-06-19 refactor: simplify current sampling, tune serial priority, and fix slider bindings
    - Remove complex midpoint-synchronized current sampling logic and TIM1 interrupts from src/main.c.
    - Perform direct synchronous ADC current reads with calibrated offset and scaling (slope = 1.480 mA/count).
    - Increase USART1 IRQ priority and implement a 5ms inter-byte timeout to reset the packet parser state.
    - Reduce discovery scan range from IDs 0-253 to 0-127 in micropython/serial_proxy.py and gui/src/App.svelte.
    - Replace double-binding in gui/src/components/ControlDial.svelte with explicit oninput assignment handlers.
    - Increase the MicroPython reply timeout from 5ms to 8ms in micr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
    [main.c, microdrive.py, serial_proxy.py]
2026-06-25 docs: reorganize PCB images, rename generic board variant, and modernize diagrams
    - Relocate and rename PCB images (`servo_pcb_front.jpg` and `servo_pcb_back.jpg`) to `docs/images/`.
    - Embed PCB layouts and the Web GUI screenshot (`webgui.jpg`) in `README.md` with appropriate spacing and headings.
    - Rename references of "Generic Servo Board" to "Servo Board" and "Generic" form factor to "Standard" in `README.md`, `docs/hardware.md`, `docs/getting-started.md`, and
    issue templates for consistency.
    - Replace all legacy ASCII art drawings in the `docs/` folder with styled, modern Mermaid.js diagrams.
    - Optimize Mermaid layouts (text contrast in dark mode, vertical pin stack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
    [servo_pcb.kicad_pcb]
2026-06-30 fix:update pcb footprint error ,cleanup micropython code
    [servo_pcb_mg99x.kicad_pcb]

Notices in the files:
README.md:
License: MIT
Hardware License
